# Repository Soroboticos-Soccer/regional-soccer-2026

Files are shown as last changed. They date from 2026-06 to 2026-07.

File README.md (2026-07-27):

# 🤖 Sorobóticos

<p align="center">
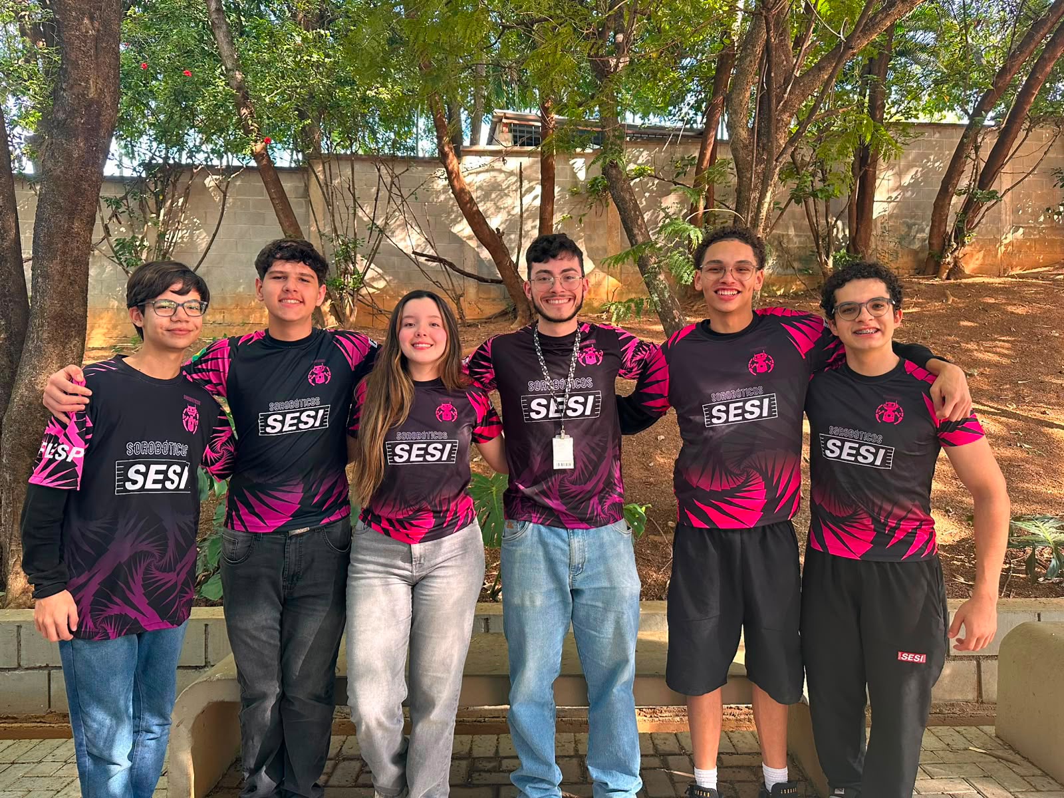
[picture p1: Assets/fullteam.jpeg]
  
</p>

<p align="center">
  <strong>Equipe de Robótica Competitiva • RoboCupJunior Soccer</strong>
</p>

---

# 👥 Sobre Nós

A **Sorobóticos Soccer** é uma equipe de robótica competitiva formada por estudantes apaixonados por tecnologia, engenharia e inovação. Nosso objetivo é desenvolver robôs autônomos capazes de atuar em partidas da modalidade **RoboCupJunior Soccer**, aplicando conhecimentos de programação, eletrônica, mecânica e manufatura digital.

A equipe acredita na aprendizagem prática como ferramenta de transformação, utilizando cada competição como uma oportunidade para evoluir tecnicamente, trabalhar em equipe e desenvolver soluções cada vez mais eficientes.

Atualmente nossos projetos são desenvolvidos com foco em:

* 🤖 Robótica Autônoma
* ⚙️ Engenharia Mecânica
* 🔌 Sistemas Embarcados
* 🧠 Algoritmos de Navegação
* 🎯 Visão Estratégica para Competições
* 🏆 RoboCupJunior Soccer

---

# 🏆 RoboCupJunior Soccer

Nosso robô foi desenvolvido para competir na categoria **Soccer Lightweight**, onde dois robôs autônomos atuam em uma partida de futebol utilizando sensores para localizar a bola, navegar pelo campo e executar estratégias ofensivas e defensivas.

---

# 📸 Nossa Equipe

<p align="center">
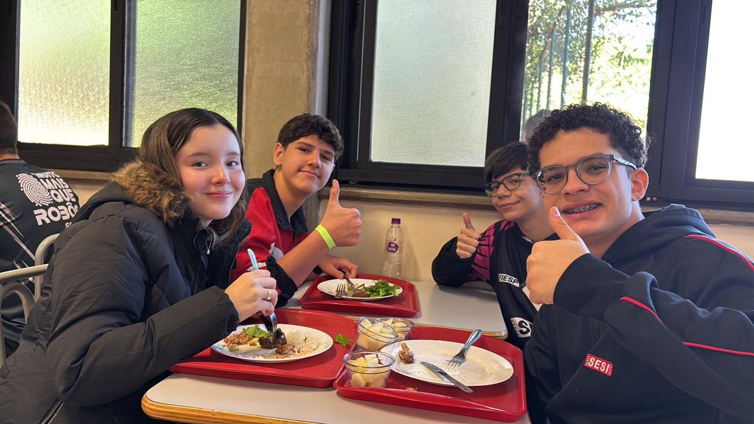
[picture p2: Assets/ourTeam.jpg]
  
</p>

---

# 🤖 Nosso Robô

<p align="center">
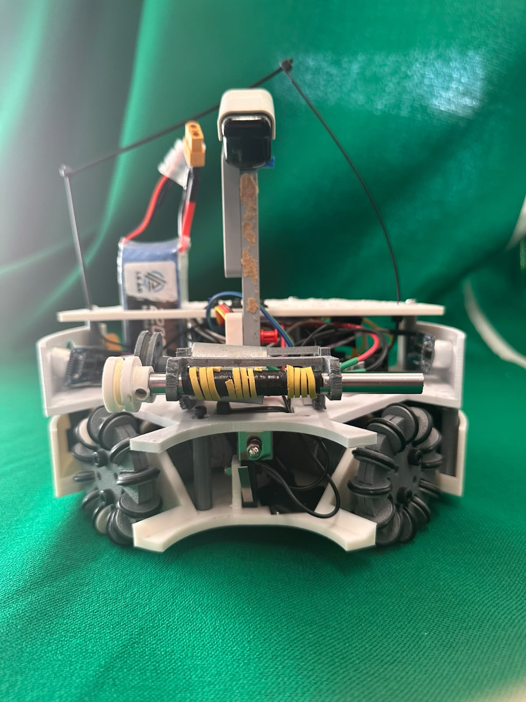
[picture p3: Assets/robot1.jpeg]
Robô Sorobóticos
  
</p>

---

# 🚀 Principais Características

### Movimentação Omnidirecional

O sistema utiliza quatro motores DC de 12V e rodas omni, permitindo movimentação em qualquer direção sem necessidade de girar o robô antes do deslocamento.

### Sistema de Dribbler

O dribbler foi desenvolvido para melhorar a captura e retenção da bola durante o jogo. O mecanismo utiliza transmissão por correias e polias para aumentar a velocidade de rotação e maximizar o controle da bola.

### Sistema de Kicker

O chute é realizado através de um mecanismo baseado em solenoide, projetado para alinhar o ponto de impacto ao centro da bola e aumentar a eficiência das finalizações.

### Posicionamento no Campo

O robô utiliza sensores ultrassônicos para estimar sua posição relativa dentro da arena e manter sua estratégia de navegação.

### Controle de Orientação

A orientação é monitorada continuamente por uma IMU, permitindo correções automáticas durante a movimentação e maior precisão nos deslocamentos.

---

# 🛠️ Hardware Utilizado

| Componente | Função |
| --- | --- |
| Arduino Mega 2560 R3 | Controle principal |
| Sensores IR TSOP4838 | Detecção da bola |
| Sensores Ultrassônicos HC-SR04 | Posicionamento |
| IMU BNO055 | Orientação |
| Drivers L298N | Controle dos motores |
| Motores DC 12V 500 RPM | Tração |
| Motor DC 12V 200 RPM | Dribbler |
| Solenoide | Kicker |
| Rodas Omni | Movimentação omnidirecional |

---

# 🏗️ Estrutura Mecânica

O chassi foi modelado em **Fusion 360** e fabricado através de impressão 3D.

### Materiais Utilizados

* TPU (Poliuretano Termoplástico)
* ABS (Acrilonitrila Butadieno Estireno)

O projeto foi otimizado para:

* Baixo centro de gravidade;
* Alta resistência a impactos;
* Facilidade de manutenção;
* Substituição rápida de componentes.

---

# 💡 Diferenciais do Projeto

### 🔧 Design Modular

O sistema foi projetado para permitir trocas rápidas de módulos críticos, reduzindo o tempo de manutenção entre partidas.

### 📡 Suporte Ajustável para Sensores IR

O suporte do sensor infravermelho permite ajustes mecânicos para adaptação a diferentes condições de campo.

### 🛡️ Chassi em TPU

A utilização de TPU proporciona absorção de impactos superior, aumentando a durabilidade da estrutura durante competições.

---

# 📈 Tecnologias Utilizadas

* Arduino IDE
* C++
* Fusion 360
* Impressão 3D
* BNO055
* HC-SR04
* TSOP4838

---

# 📧 Contato

**Sorobóticos Soccer**

📩 [soroboticossoccer@gmail.com](mailto:soroboticossoccer@gmail.com)
📬 Instagram: [@_soroboticos](https://www.instagram.com/_soroboticos/)

---

<p align="center">
Desenvolvido com dedicação pela equipe Sorobóticos⚽🤖
</p>

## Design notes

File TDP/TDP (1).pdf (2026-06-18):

Nome do Time

Qual é o nome do seu time?

Sorobóticos

Liga

De qual liga você está participando?

Infrared League

País

De onde vocês são?

Sorocaba, São Paulo, Brasil

Contato

Se outros times tiverem dúvidas sobre o seu robô, agora ou no futuro, qual(is) endereço(s) de e-mail nós podemos disponibilizar através desse documento para entrarem em contato?

E-mails aqui:

### - brunoproencasilva@gmail.com - gabriela.reche09@gmail.com - heitor.f.souto@gmail.com - hcabral.008@gmail.com

Redes Sociais

Link das redes sociais do time (se tiver)

Link aqui:

### https://www.instagram.com/_soroboticos?utm_source=ig_web_button_share_sheet&i

gsh=ZDNlZDc0MzIxNw== (https://www.instagram.com/_soroboticos?utm_source=ig_web_button_share_sheet&igsh=ZDNlZDc0MzIxNw==)

Foto do time

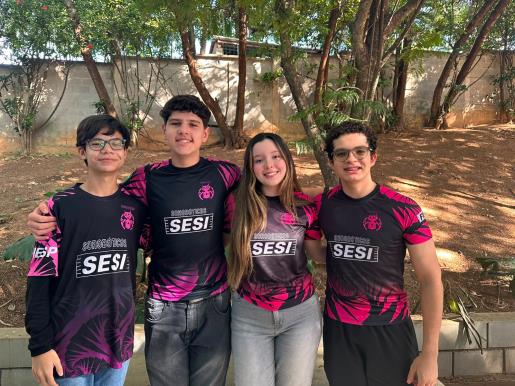
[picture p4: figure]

Membros & Funções

Qual é o nome de cada membro e quais são as suas funções:

- Bruno Proença: Integrador de Software;
- Henrique Cabral: Desenvolvedor de Software;
- Gabriela Reche: Projetista Mecânica;
- Heitor Ferreira: Integrador de Hardware.

Frequência de Reuniões

Com qual frequência o time de vocês se encontra?

Nos reunimos presencialmente de 3-5 vezes por semana. Além dos encontros presenciais, também mantemos comunicação frequente de forma online para discutir programação, eletrônica, mecânica e planejamento da estratégia.

Local das Reuniões

Onde vocês se reunem para trabalhar no robô?

Nos reunimos no espaço Fab Lab de nossa escola, onde temos acesso às ferramentas, equipamentos e recursos necessários para o desenvolvimento dos robôs.

Data de Início

Quando o seu time começou a trabalhar no robô desse ano?

Nós começamos a trabalhar no robô este ano, em maio, iniciando o planejamento das estratégias, o desenvolvimento mecânico e a programação dos sistemas do robô.

Competições Passadas

Em quais competições da RoboCupJunior vocês já participaram e em quais ligas?

A equipe já participou duas vezes da modalidade RoboCupJunior Rescue Maze, adquirindo experiência em programação, estratégia e resolução de desafios autônomos, ampliando nossos conhecimentos em robótica, trabalho em equipe e desenvolvimento de projetos tecnológicos.

Para dois integrantes da equipe, esta será a primeira experiência em competições práticas de robótica.

Contribuição do Mentor

Quais partes do trabalho que mais tiveram a contribuição do mentor?

Nosso mentor teve uma contribuição importante principalmente no ensino de modelagem 3D e utilização do Fusion, além de auxiliar no planejamento e organização do projeto. Ele também nos orientou em decisões relacionadas ao design do robô, estratégias de jogo e desenvolvimento geral da equipe, facilitando nosso aprendizado e guiando o grupo durante todas as etapas do projeto.

Gerenciamento de Tarefas

Como vocês gerenciaram as tarefas da equipe?

No início de cada semana, utilizamos um quadro Kanban para organizar e gerenciar as tarefas da equipe. Por meio dessa metodologia, distribuímos as atividades entre os integrantes, acompanhávamos o progresso do projeto e definíamos prioridades para as tarefas mais importantes, garantindo uma melhor organização, comunicação e eficiência no desenvolvimento do robô.

Ferramentas de IA

Quais ferramentas de IA vocês utilizaram?

Utilizamos ferramentas de inteligência artificial como ChatGPT, Gemini e Claude para auxiliar no desenvolvimento do projeto, principalmente na programação de novos componentes, otimização de algoritmos e identificação de erros no código.

Robô 1 Geral

Vista Geral do Robô 1

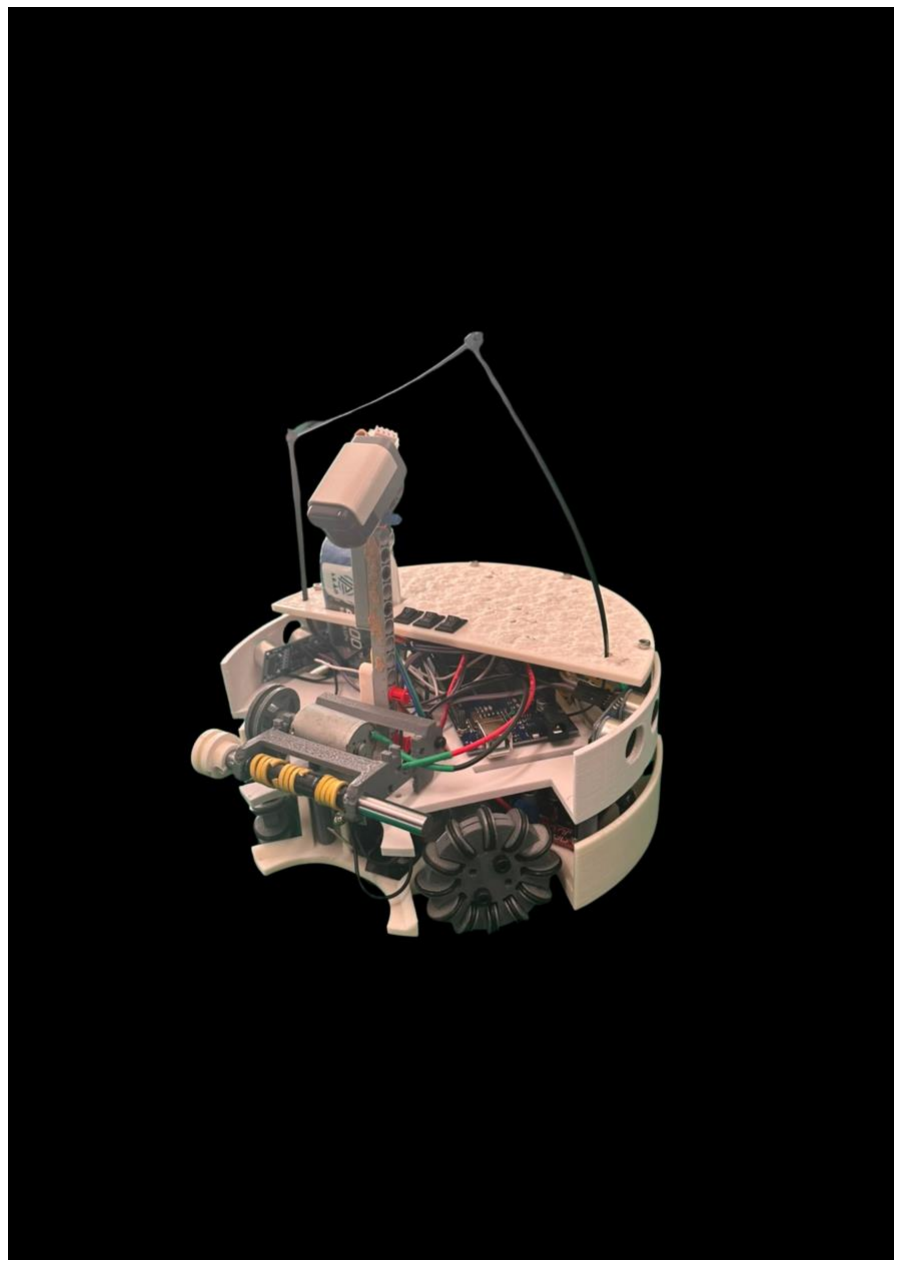
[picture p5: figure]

Robô 1 Frente

Vista Frontal do Robô 1

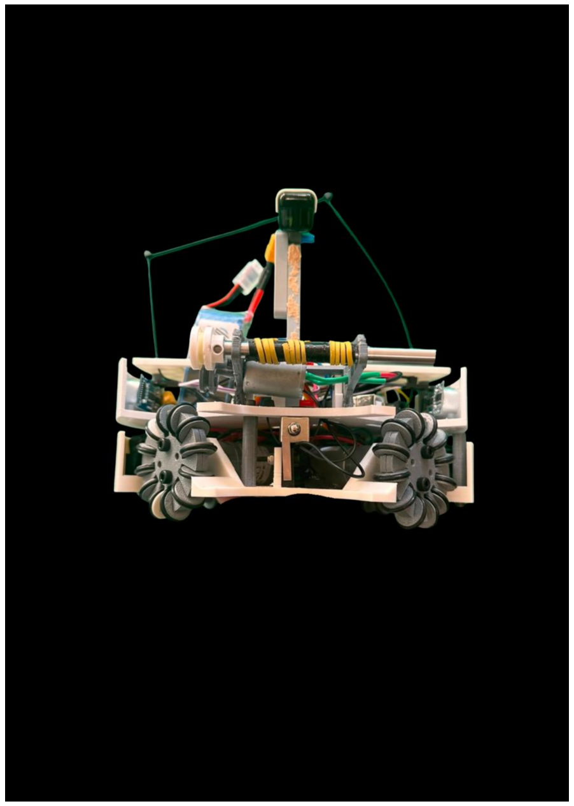
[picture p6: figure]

Robô 1 Traseira

Vista Traseira do Robô 1

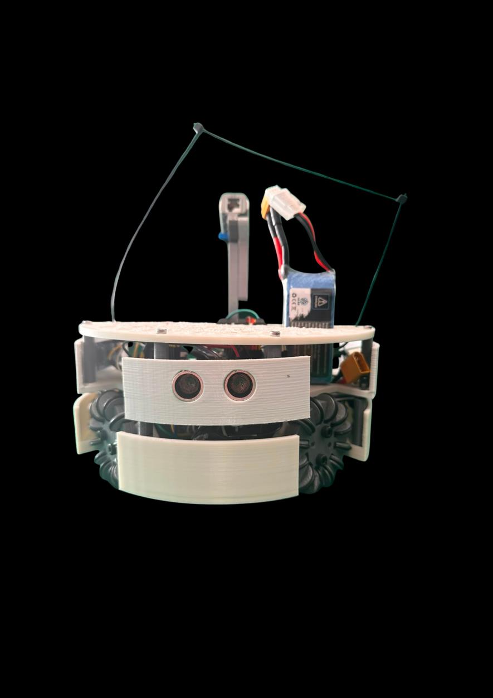
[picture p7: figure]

Robô 1 Superior

Vista Superior do Robô 1

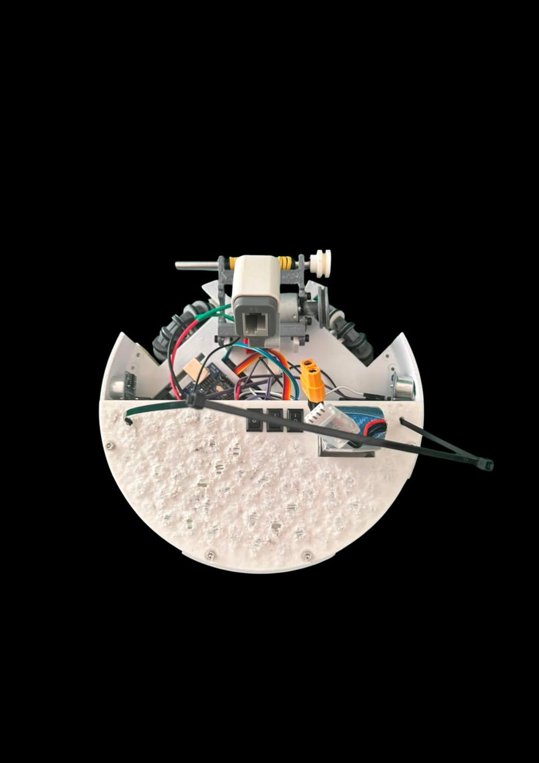
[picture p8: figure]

Robô 1 Inferior

Vista Inferior do Robô 1

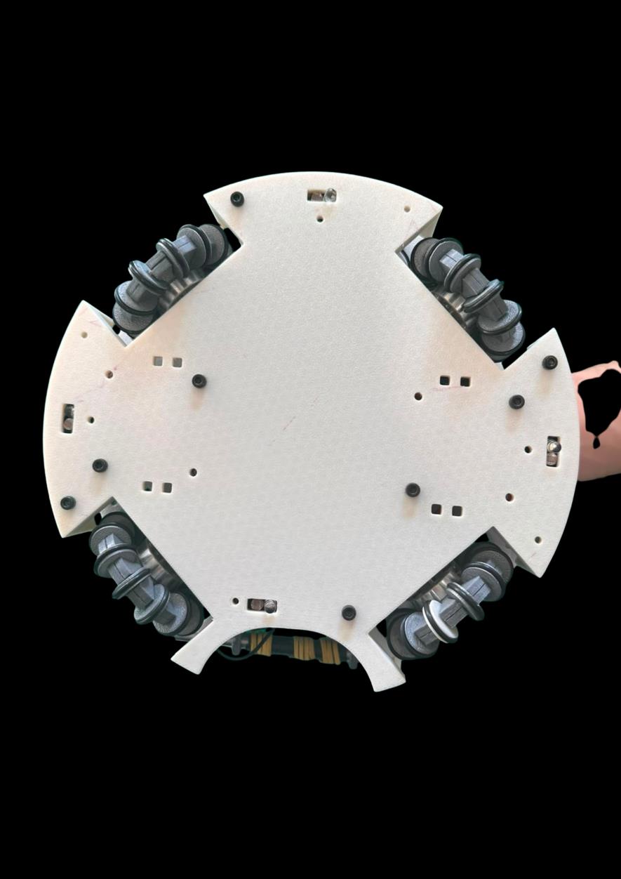
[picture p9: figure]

Robô 1 Lateral Direita

### Vista Lateral Direita do Robô 1

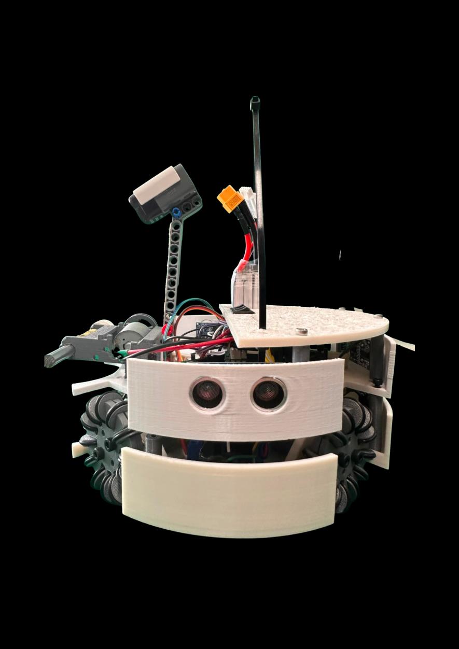
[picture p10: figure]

Robô 1 Lateral Esquerda

Vista Lateral do Robô 1

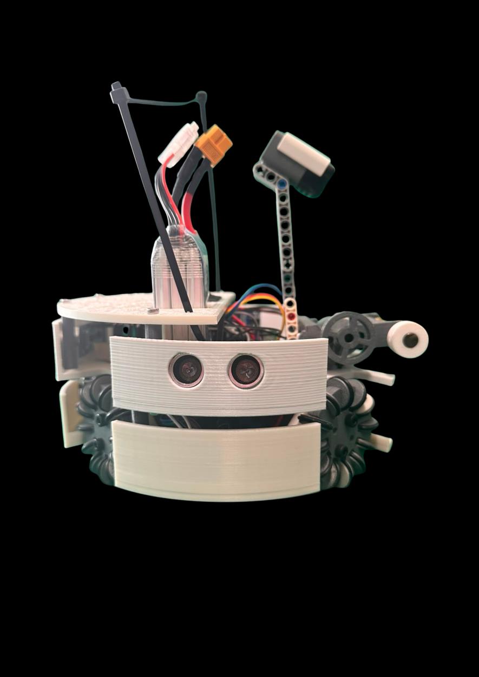
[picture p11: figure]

Posicionamento e Movimentação

Como você localiza o robô dentro do campo e como você utiliza essa localização para movimentá-lo?

Nosso robô utiliza sensores LDR, sensores ultrassônicos e sensor giroscópio para orientação e localização dentro do campo. O sensor giroscópio é responsável por manter os robôs sempre orientados em direção ao lado adversário, garantindo maior estabilidade e precisão durante a movimentação.

Já os sensores ultrassônicos permitem estimar a posição do robô no campo por meio da obtenção de coordenadas aproximadas nos eixos X e Y. Com essas informações, conseguimos implementar movimentações mais estratégicas, como direcionar o robô para posições específicas durante o ataque, facilitando o alinhamento e a realização dos chutes.

Durante o desenvolvimento, tivemos bastante cautela na implementação dos sensores ultrassônicos devido à possibilidade de interferências causadas por outros robôs e pela própria bola, realizando testes e ajustes para aumentar a confiabilidade da leitura durante as partidas.

Robô 2 Geral

Vista Geral do Robô 2

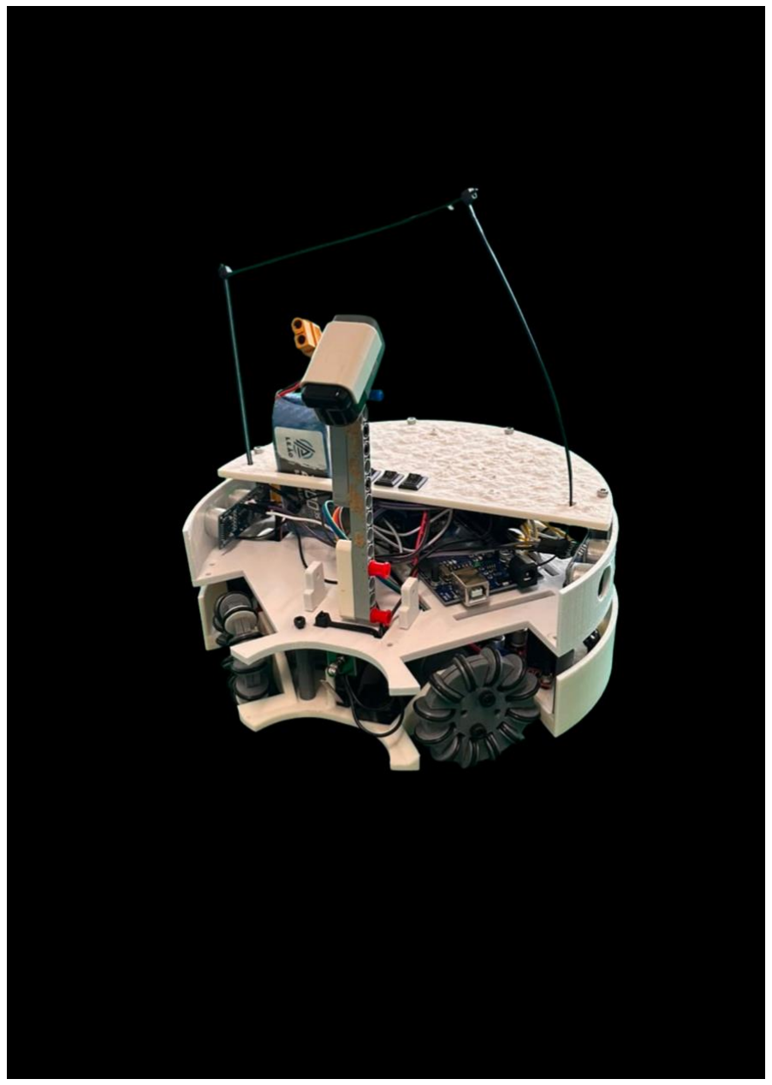
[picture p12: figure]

Frente Robô 2

Vista Frontal do Robô 2

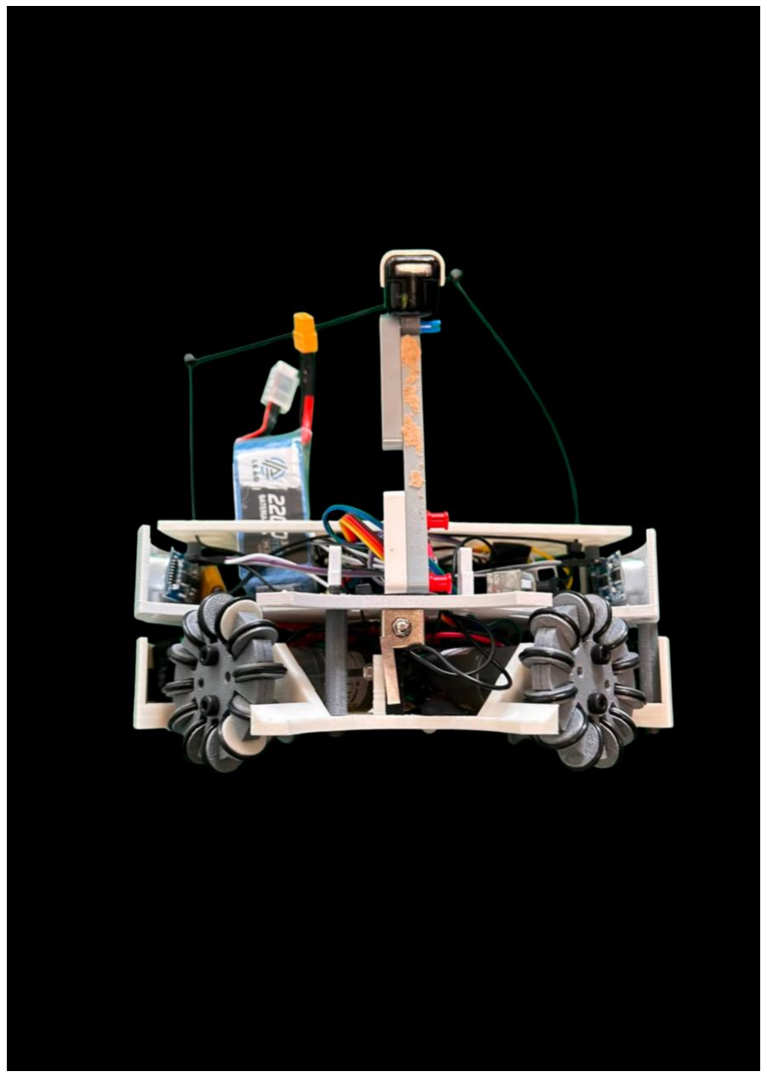
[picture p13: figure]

Robô 2 Traseira

Vista Traseira do Robô 2

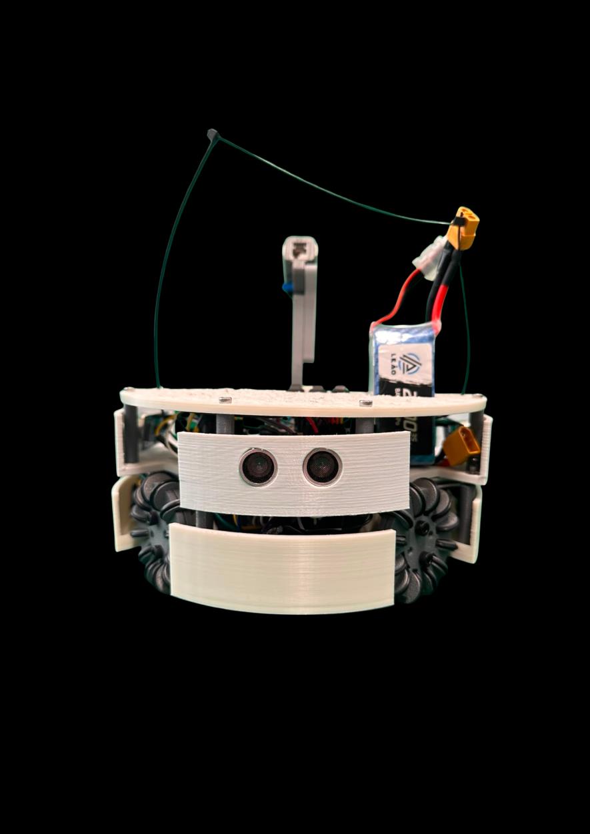
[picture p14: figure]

Robô 2 Superior

Vista Superior do Robô 2

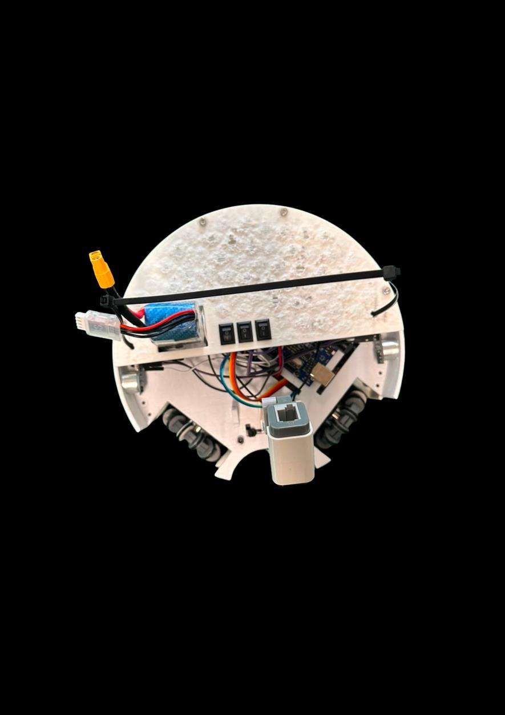
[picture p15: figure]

Robô 2 Inferior

Vista Inferior do Robô 2

Robo2 Lateral Direita

Vista Lateral Direita do Robô 2

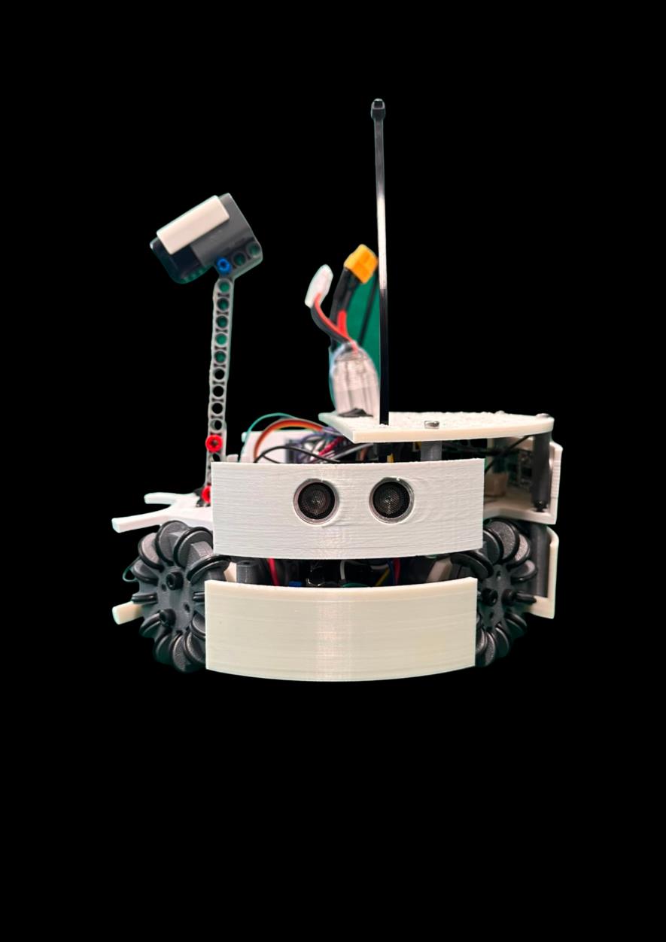
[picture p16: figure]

Robô 2 Lateral Esquerda

Vista Lateral Esquerda do Robô 2

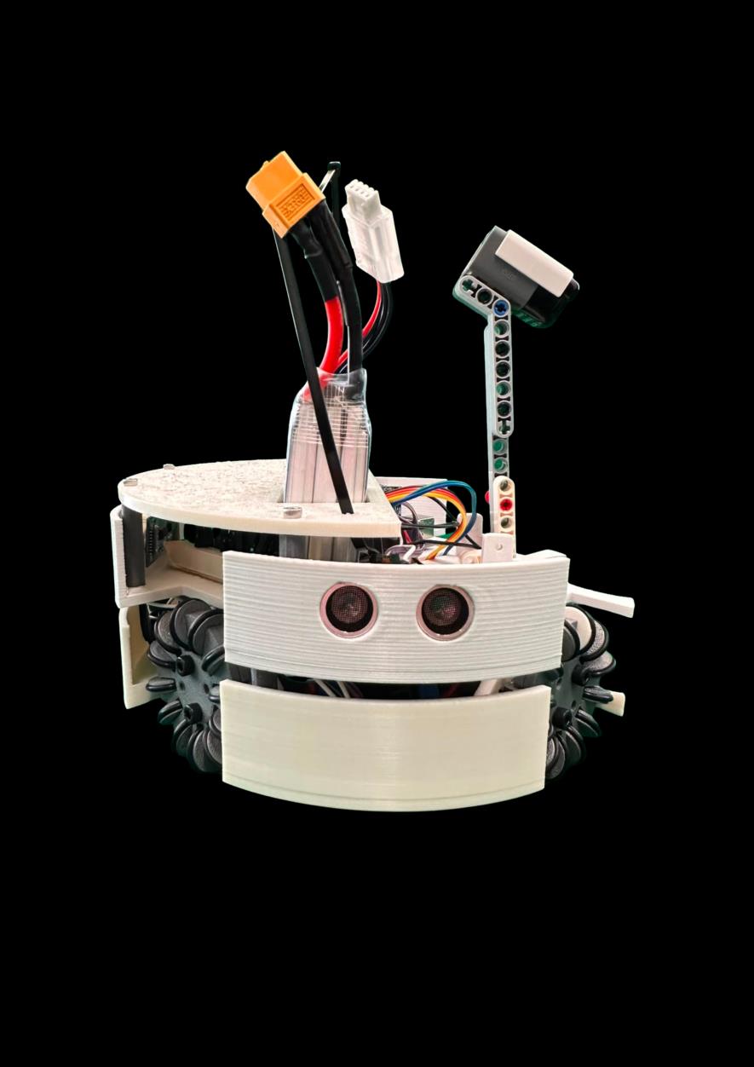
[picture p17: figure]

Design Mecânico

Como vocês fizeram o design das partes mecânicas do seu robô?

Para o desenvolvimento das partes mecânicas, utilizamos o Fusion 360 para modelar o chassi e os principais componentes do robô. Diversas iterações de projeto e testes foram realizadas ao longo do desenvolvimento, permitindo otimizar a estrutura e o desempenho mecânico do sistema.

A fabricação das peças foi realizada por impressão 3D, garantindo alta precisão e eficiência na prototipagem. Também conduzimos um estudo dos materiais e dos padrões de preenchimento (infill), optando pela estrutura do tipo favo de mel

(honeycomb) devido à sua excelente relação entre resistência mecânica e peso reduzido.

O TPU (Poliuretano Termoplástico) foi empregado em regiões sujeitas a impactos, aproveitando suas propriedades flexíveis e sua capacidade de absorção de energia. Já o ABS (Acrilonitrila Butadieno Estireno) foi utilizado em componentes que exigem maior rigidez e resistência mecânica, como o dribbler.

O projeto final adotou um chassi circular com posições específicas para cada componente, facilitando a organização interna e a manutenção. Recursos visuais também foram incorporados para simplificar a identificação dos elementos eletrônicos e mecânicos. Além disso, peças como as rodas e o dribbler foram projetadas no Fusion 360 para garantir perfeita integração ao conjunto. A distribuição dos componentes foi planejada para manter um baixo centro de gravidade, aumentando a estabilidade do robô durante deslocamentos, colisões e mudanças rápidas de direção. Essa combinação de design, materiais e técnicas de fabricação resultou em uma estrutura leve, resistente e de fácil manutenção.

Método de Construção

Como você construiu o seu design?

Como vocês construíram o seu design?

Nossa estratégia de desenvolvimento consistiu na utilização de um robô de testes, que foi modificado manualmente ao longo do projeto. A estrutura foi lixada, ajustada e adaptada diversas vezes até que obtivéssemos um resultado próximo ao esperado. Essa abordagem permitiu realizar testes mecânicos e de programação sem a necessidade de imprimir um novo chassi a cada alteração, reduzindo significativamente o consumo de filamento e o tempo de desenvolvimento.

Após a validação dos principais conceitos no robô de testes, fabricamos o chassi definitivo por impressão 3D, incorporando todas as melhorias identificadas durante os experimentos. As demais peças produzidas por manufatura aditiva, como suportes, rodas e componentes do dribbler, seguiram a mesma metodologia: inicialmente eram testadas e ajustadas em protótipos, e somente após sua validação eram impressas em sua versão final.

Em seguida, realizamos a montagem completa do robô, instalando os sistemas mecânicos, eletrônicos e de controle. Por fim, novos testes foram conduzidos para verificar a integração entre os componentes e garantir o desempenho, a estabilidade e a confiabilidade do sistema durante as partidas.

Motores e Razão

Quantos motores vocês usaram e por quê?

A movimentação do robô é realizada por quatro motores de corrente contínua de 12 V e 500 RPM, cada um acoplado a uma roda omni, permitindo deslocamentos em múltiplas direções e maior liberdade de movimentação. Para o sistema de dribbler, foi empregado um motor de corrente contínua de 12 V e 200 RPM, responsável pela rotação do dribbler, que auxilia no controle e na retenção da bola durante as partidas.

Design do Kicker

Se o robô tiver um kicker, explique como foi projetado e contruído o mecanismo do kicker?

Em nosso robô, o kicker foi projetado para aumentar a potência e a eficiência dos chutes, proporcionando maior velocidade de saída da bola e contribuindo para a precisão das jogadas. O mecanismo foi desenvolvido de forma a alinhar o ponto de impacto com o centro da bola, maximizando a transferência de energia durante o chute.

Para isso, o kicker foi instalado logo abaixo do dribbler, entre os dois chassis do robô, sendo o único componente localizado neste local no robô. garantindo um posicionamento centralizado em relação à bola quando esta é controlada pelo sistema de drible. Essa configuração reduz desalinhamentos no momento do impacto, melhora a consistência dos chutes e contribui para um desempenho mais confiável durante as partidas.

Além disso, sua estrutura foi projetada para ser compacta e robusta, permitindo integração eficiente com os demais sistemas do robô sem comprometer a estabilidade ou a mobilidade da plataforma.

Design do Dribbler

Se o robô tiver um dribbler, explique como vocês projetaram e construiram o mecanismo do dribbler. ... If your robot has a dribbler, explain how you designed and built the mechanics of the dribbler.

O dribbler foi projetado para garantir o controle eficiente da bola durante a movimentação do robô. O mecanismo é composto por um eixo metálico acionado por um motor de alta rotação, sendo o eixo revestido com fita dupla face para aumentar o atrito e, consequentemente, a aderência durante o contato com a bola.

Para potencializar o desempenho do sistema, utilizamos um conjunto de polias e correias para transmitir o movimento do motor ao eixo metálico, configurado de forma a aumentar a velocidade de rotação do dribbler. Essa solução permitiu obter uma maior velocidade tangencial na superfície de contato com a bola, melhorando sua captação e condução.

Durante o processo de desenvolvimento, o dispositivo foi modelado de forma a maximizar a área de contato entre o dribbler e a bola, proporcionando maior tração e estabilidade na condução. Seu posicionamento e geometria foram cuidadosamente definidos para manter a bola próxima ao robô, reduzindo a possibilidade de perda de controle durante acelerações, frenagens e mudanças bruscas de direção.

Inovação Mecânica

Inovação Mecânica

O desenvolvimento mecânico do nosso robô priorizou soluções que garantissem manutenibilidade rápida, adaptabilidade às condições da arena e eficiência dinâmica. Destacam-se três pilares fundamentais no nosso design:

- Design Modular de Alta Eficiência: Desenvolvido no software Fusion 360 e fabricado via impressão 3D em TPU, o chassi foi estruturado sob uma perspectiva estritamente modular. Esse arranjo estratégico permite que os conjuntos de rodas omnidirecionais ou o módulo do dribbler sejam completamente substituídos em menos de dois minutos, garantindo agilidade em reparos críticos nos intervalos entre as partidas.
- Suporte Ajustável para o Sensor IR: O suporte que aloja o receptor infravermelho conta com um sistema de regulagem geométrica. Essa flexibilidade mecânica facilita o processo de calibração física do componente, permitindo adequar rapidamente o ângulo de leitura do sensor para otimizar o rastreamento da bola de acordo com as variações e características específicas de diferentes campos.

Diagrama da Eletrônica

Forneça-nos um diagrama da eletrônica do seu robô

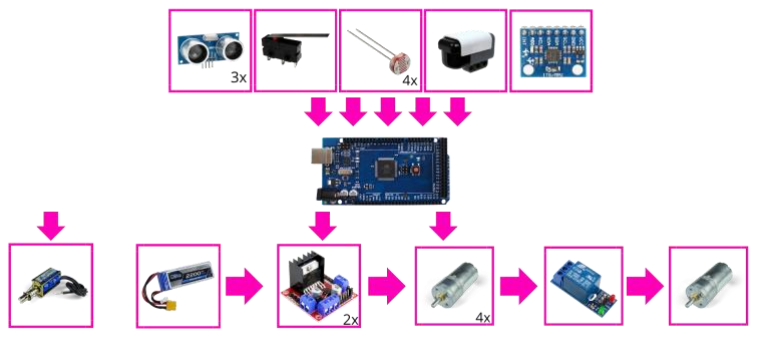
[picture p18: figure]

Circuito de Energia

Como o circuito de energia funciona?

Utilizamos duas baterias independentes para distribuir a alimentação do robô de forma mais eficiente. Uma bateria de 11,1 V é dedicada aos motores de movimentação e ao dribbler, garantindo corrente suficiente para os componentes de maior consumo. A segunda bateria, de 7,4 V, alimenta o Arduino, que por sua vez fornece energia aos sensores e demais componentes eletrônicos de controle. Essa separação reduz interferências causadas pelos motores, aumentando a estabilidade e a confiabilidade do sistema durante as partidas.

Circuito do Motor

Como você controla os motores? Explique os circuitos que você utiliza para isso.

Foram utilizadas duas placas driver L298N para o acionamento dos motores de tração e uma terceira placa dedicada ao sistema do dribbler. A interface de controle é realizada por meio de um Arduino, responsável pela geração dos sinais de modulação por largura de pulso (PWM). Cada motor é acionado por três pinos de controle, sendo dois destinados à definição do sentido de rotação e um utilizado para o controle da velocidade por PWM, permitindo um ajuste preciso do desempenho do sistema.

Microcontrolador & Razão

Qual tipo de microcontrolador ou placa vocês usaram para o robô? Por que você decidiu usar essa peça para o seu robô? Se o usou mais de um processador, explique-os separadamente

Para o controlo central do robô, a equipa selecionou a placa Arduino Mega 2560 R3. A escolha deste microcontrolador baseou-se na sua robustez, ampla capacidade de conectividade e fiabilidade no processamento de dados em tempo real, atendendo perfeitamente às exigências dinâmicas da RoboCup:
- Capacidade de Processamento e Memória: Equipado com o chip ATmega2560 e 256 KB de memória Flash, o controlador possui a capacidade ideal para armazenar e executar com fluidez toda a lógica de jogo, os algoritmos de tomada de decisão e a filtragem das leituras dos sensores, garantindo um tempo de resposta imediato em campo.
- Ampla Disponibilidade de Portas (I/O): Com 54 pinos digitais e 16 entradas analógicas, a placa permite a integração simultânea e direta de todos os periféricos do projeto. Isto inclui a rede de sensores (recetor IR TSOP4838, IMU BNO055 e sensores de luminosidade) e os atuadores (motores de tração de 12V e o sistema do dribbler), eliminando a necessidade de expansores de portas que poderiam introduzir latência.
- Padronização e Robustez (Revisão R3): O formato padrão da revisão R3 oferece excelente estabilidade mecânica e elétrica. Esta característica mecânica facilita o acoplamento de shields dedicados ou placas de circuito impresso (PCBs) personalizadas para a distribuição de energia e acionamento dos motores, o que otimiza a organização interna do chassi de TPU e assegura ligações firmes e resistentes aos impactos das partidas.

Detecção da Bola

Como o seu sensor de detecção da bola e/ou sua câmera(s) funciona?

Para a identificação da bolinha de infravermelho, o robô atacante utiliza o sensor HiTechnic InfraRed Seeker. Esse sensor é responsável por detectar a direção do sinal infravermelho emitido pela bolinha e auxiliar na orientação do robô, guiando-o de forma mais precisa em sua direção. Já o robô goleiro utiliza o sensor TSOP4838, empregado na recepção de sinais infravermelhos modulados em 38 kHz para a detecção da bola. Dessa forma, cada robô adota uma estratégia distinta de sensoriamento infravermelho, adequada à sua função dentro da equipe, contribuindo para um melhor desempenho durante as partidas.

A partir dessas duas variáveis, nosso robô consegue identificar com precisão a posição e a distância da bola, permitindo uma movimentação eficiente e confiável para alcançá-la durante as partidas.

Detecção da Linha

Como o circuito de detecção de linha do seu robô funciona?

Utilizamos quatro sensores LDR posicionados estrategicamente para garantir que o robô não ultrapasse a linha branca do campo. Cada sensor é alimentado com 5V e conectado a um circuito pull-down utilizando um resistor de 10 kΩ. A saída de cada sensor é ligada a uma entrada analógica do microcontrolador, permitindo a leitura contínua dos valores de luminosidade.

Quando os sensores detectam a diferença de reflexão entre o campo escuro e a linha branca, o microcontrolador interpreta essa variação e executa rapidamente movimentos corretivos para impedir que o robô saia da área de jogo.

Sensores de Posição/Navegação

Quais sensores vocês usaram para a navegação e como eles são conectados com o processador? Quais sensores vocês para se posicionar no campo? E quanto ao senso de direção do robô?

Para a navegação e posicionamento no campo, utilizamos três sensores ultrassônicos conectados diretamente ao microcontrolador do robô por meio de portas digitais de entrada e saída. Esses sensores medem continuamente a distância até as bordas da quadra, permitindo estimar a posição do robô nos eixos X e Y. Com essas informações, o sistema consegue determinar sua localização aproximada dentro do campo e ajustar sua trajetória quando necessário.

Além dos sensores ultrassônicos, utilizamos o sensor inercial MPU6050, que integra acelerômetro e giroscópio. Esse sensor é conectado ao processador através da comunicação I²C e fornece informações sobre a orientação angular do robô em

tempo real.

O MPU6050 é responsável pelo senso de direção do robô, permitindo a realização de giros precisos e o controle do ângulo do chute.

Circuito do Kicker

Como vocês conduziram o sistema do kicker? Como como o circuito do kicker faz ele funcionar?

Utilizamos um sistema de kicker baseado em um solenoide, responsável por gerar a força necessária para impulsionar a bola. O solenoide recebe alimentação diretamente da bateria do robô, enquanto o acionamento é controlado por um relé conectado a uma porta digital do microcontrolador.

Quando o microcontrolador identifica a condição ideal para o chute, ele envia um sinal ao relé, permitindo a passagem de corrente para o solenoide. Isso gera um movimento rápido e forte no mecanismo de chute, possibilitando finalizações mais eficientes durante as partidas.

Circuito do Dribbler

Como o sistema do seu dribbler funciona? Quais componentes e circuitos vocês usaram para controlá-lo?

We designed a dribbler system to help the robot capture and maintain control of the ball while moving, allowing it to perform passes, dribbles, shots, and both offensive and defensive maneuvers with greater precision. The dribbler also prevents the ball from rolling away or being easily taken by opponents. It is powered by a motor connected to the L298N board, which drives a gear system to keep the ball securely in place. When the robot approaches the opponent’s goal, the motor reverses direction, releasing the ball to attempt a goal.

PCB

PCB do robô .... PCB of your robot

Não utilizamos placa de circuito personalizado.

Inovação

Inovações

O elemento de maior orgulho no desenvolvimento do nosso robô é o chassi personalizado, projetado no Fusion 360 e impresso em 3D utilizando Poliuretano Termoplástico (TPU) rosa. A utilização deste material maleável e de alta tenacidade otimiza significativamente a absorção de impactos mecânicos e estabelece um casulo protetor altamente eficiente e resiliente para toda a eletrônica e rede de sensores embarcados.

O resultado é uma estabilidade estrutural notável, reduzindo drasticamente o risco de fraturas ou desalinhamentos físicos que tipicamente ocorrem com o uso de plásticos rígidos convencionais sob as constantes colisões de alta velocidade da modalidade Soccer. Além disso, as propriedades elásticas e a flexibilidade controlada do TPU permitiram projetar geometrias de encaixe sob pressão, o que simplifica consideravelmente a manutenção interna e acelera a substituição rápida de componentes nos boxes entre as partidas.

Controle do Motor

Como o processador é usado para controlar os motores?

A arquitetura de controle do robô é baseada no microcontrolador Arduino Mega 2560 R3, que se comunica com dois módulos driver L298N em ponte H dupla para gerenciar o sistema de rotação. Cada motor de corrente contínua é acionado por três linhas de controle: dois pinos digitais (IN1 e IN2) definem o sentido de rotação, enquanto um pino de habilitação (EN) regula a velocidade e a potência via sinais de Modulação por Largura de Pulso (PWM) do microcontrolador.

Método de Detecção da Bola

Como o robô detecta a bola? Como o robô lê os dados do sensor de detecção da bola ou da câmera?

Para a localização da bola em campo, o robô utiliza uma estratégia de rastreamento baseada em sensores receptores de infravermelho TSOP4838, componentes fundamentais para detectar com precisão os sinais de IR modulados emitidos pela bola oficial da RoboCup:

- Captação de Sinais Modulados: O sensor TSOP4838 é projetado especificamente para sintonizar a frequência de modulação da bola (frequentemente em 38 kHz), o que mitiga a interferência de fontes de luz externa e da iluminação ambiente do local da competição.
- Processamento de Dados e Direção: Os sinais captados pelos receptores são enviados diretamente para o Arduino Mega 2560 R3. O microcontrolador processa essas leituras em tempo real, mapeando a intensidade e a temporização dos pulsos captados para calcular valores numéricos correspondentes à direção e proximidade da bola em relação ao eixo central do robô.
- Integração com o Código: Por meio de rotinas de software e filtros digitais implementados na IDE do Arduino, os dados brutos dos sensores são
convertidos | rapidamente | em | informações | direcionais | limpas. | Esse
processamento contínuo serve como entrada imediata para o algoritmo de navegação omnidirecional, permitindo que o robô reaja instantaneamente a mudanças na trajetória da bola com alta agilidade.

Algoritmo de Condução da Bola

Como o algoritmo de pegar a bola funciona? Há alguma diferença entre os robôs na forma que eles se movem em direção à bola?

Ambos os robôs utilizam os valores de direção e intensidade fornecidos pelo sensor de bola para localizar e se mover em direção a ela. No entanto, cada um possui uma estratégia diferente de acordo com sua função na equipe.

O robô atacante procura se posicionar atrás da bola, mantendo-a entre ele e o gol adversário. Isso facilita o controle da bola e melhora a eficiência dos ataques, evitando rotações desnecessárias durante a movimentação.

Já o robô goleiro move-se na direção da bola para realizar bloqueios, mas sua movimentação é limitada à área defensiva. Ele nunca sai da linha de pênalti, garantindo que permaneça em uma posição adequada para proteger o gol.

Algoritmo da Linha

Como o seu robô identifica a linha para se manter dentro do campo? Quais algoritmos foram usados para evitar que o robô saia da area?

O robô utiliza sensores de refletância LDR posicionados na parte inferior da estrutura para detectar as linhas brancas que delimitam o campo. A leitura desses sensores é realizada continuamente no loop principal de controle, garantindo resposta rápida a qualquer aproximação das bordas.

O algoritmo implementado é baseado em uma lógica reativa de prioridade. Sempre que um dos sensores identifica a linha (valor acima do limiar definido durante a calibração), o evento recebe prioridade sobre as demais ações do robô. Nesse momento, o sistema interrompe temporariamente o comportamento atual e executa um movimento na direção oposta ao sensor acionado.

Algoritmo de Gols

Quais algoritmos vocês usaram para marcar gols? Como vocês usaram o dribbler e o kicker para conduzir a bola?

Quando o robô detecta que está com posse de bola por meio do sensor de switch, ele inicia automaticamente o modo de ataque. A partir desse momento, o comportamento ofensivo varia de acordo com a posição do robô em campo, podendo avançar pela esquerda, pela direita ou diretamente em direção ao gol caso já esteja em uma posição favorável.

Durante a condução da bola, o robô pode se mover de costas utilizando o dribbler para manter o controle da bola e aumentar a distância em relação aos adversários, reduzindo o risco de perda de posse. Quando atinge uma distância ou ângulo adequado em relação ao gol, o robô realiza o alinhamento final por meio de rotação e aciona o kicker para efetuar o chute.

Algoritmo de Defesa

Quais algoritmos vocês usaram para impedir que o time adversario marque gols? Como os seus robôs defendem o proprio gol?

Quando o robô atacante não está com a posse da bola, ele se desloca continuamente em direção à sua posição para tentar recuperá-la. Esse comportamento também ajuda a pressionar o adversário e dificultar sua progressão, sem recuar excessivamente no campo para não interferir na atuação do goleiro.

O robô goleiro permanece prioritariamente posicionado na linha de pênalti, garantindo a proteção constante do gol. A partir dessa posição, ele acompanha a movimentação da bola e realiza bloqueios quando necessário. Em situações específicas, quando a bola está próxima e parada por um curto período, o goleiro avança temporariamente para afastá-la ou chutá-la em direção ao campo adversário, retornando em seguida à sua posição defensiva.

Comunicação do Robô

Os seus robôs se comunicam entre si? Como vocês usam essa comunicação para obter vantagem?

Os robôs não possuem comunicação direta entre si durante a partida. No entanto, cada um é programado com funções bem definidas, atacante e goleiro, o que garante um comportamento coordenado e complementar em campo. Essa divisão de papéis evita conflitos de decisão e reduz a chance de os robôs se atrapalharem, permitindo que atuem de forma harmônica.

Link GitHub

Link do GitHub

### https://github.com/Soroboticos-Soccer/regional-soccer-2026

Lista de Materiais

Lista de Materiais

ListaPreço.xlsx (https://sesisenaispedu-my.sharepoint.com/:x:/g/personal/antoni_frigerio_portalsesisp_org_br/IQARvzUoNFhvR7zJtImBCNMOAaJihk4XXiH-QJTbcqsfziY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)

Custo

Quanto custou para construir o robô?

Robôs (componentes em uso): 2169 BRL;

Experimentos (falhas de construção, quebra, hardware.): 2847 BRL;

Fundos

Como vocês conseguiram os fundos para construir o robô

Todos os gastos foram custeados pela escola SESI

Acessibilidade

Quão accessivel foi para completar o RoboCupJunior Soccer

Conferir Respostas

Vocês conferiu todas as suas respostas?

Sim!

Consentimento de Publicação

Nos publicamos os TDPs e os Posters durante ou depois da competição como descrito no início

Endereço de E-mail

Endereço de e-mail

### soroboticossoccer@gmail.com

Arquivo TDP

### https://github.com/Soroboticos-Soccer/regional-soccer-2026/tree/main/TDP

Extra Column

Column 67

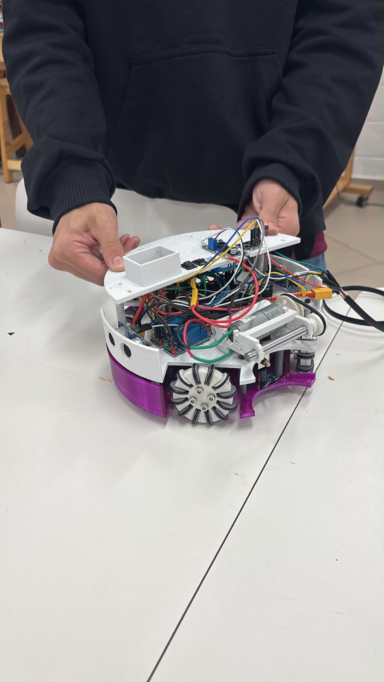
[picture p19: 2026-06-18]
Assets/robot.jpg

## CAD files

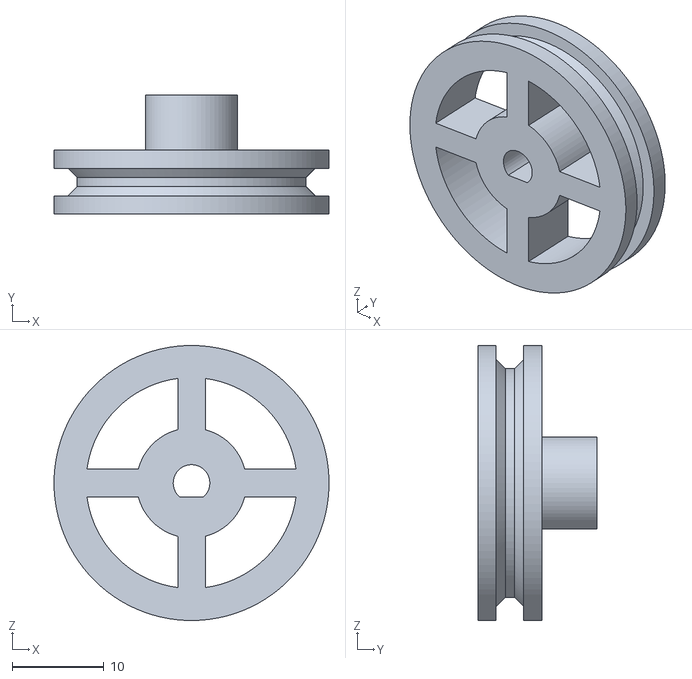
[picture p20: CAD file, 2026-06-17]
Projetos Mecânicos/polia_3cm (1).stl
30.0 x 13.0 x 30.0

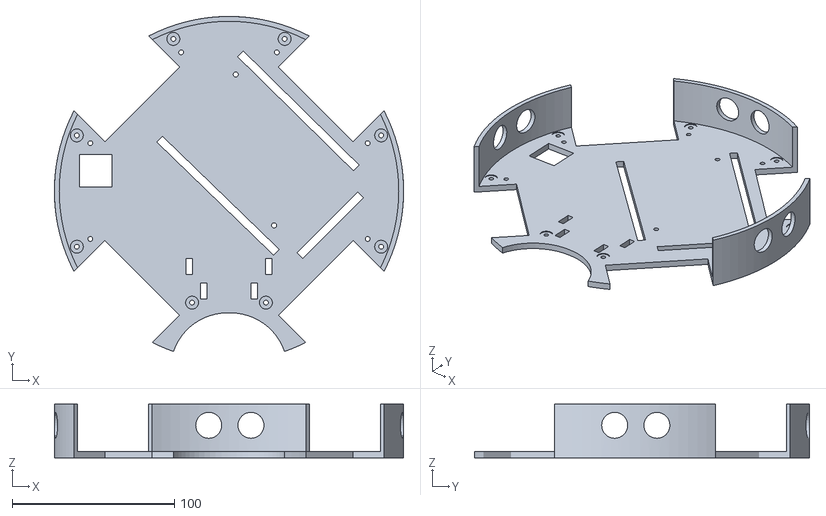
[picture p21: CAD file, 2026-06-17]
Projetos Mecânicos/chassi_soccer_meio.stl
214.9 x 206.2 x 33.0

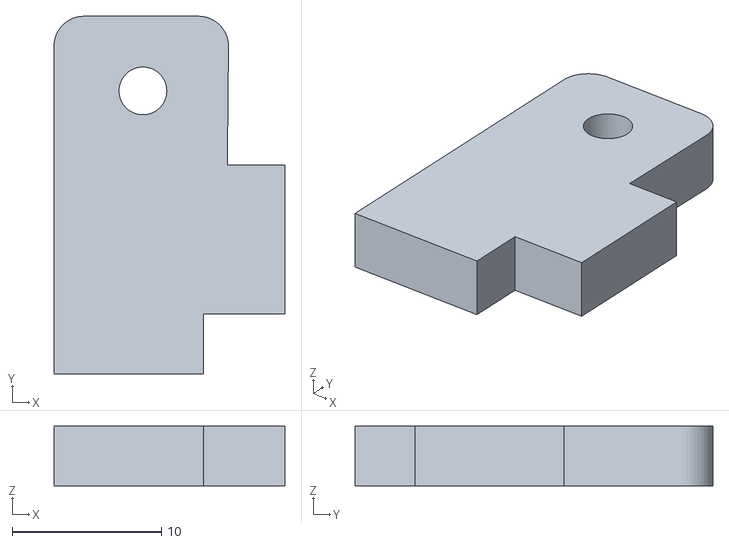
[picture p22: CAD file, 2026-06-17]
Projetos Mecânicos/dribler teste (6).stl
15.5 x 23.9 x 4.00

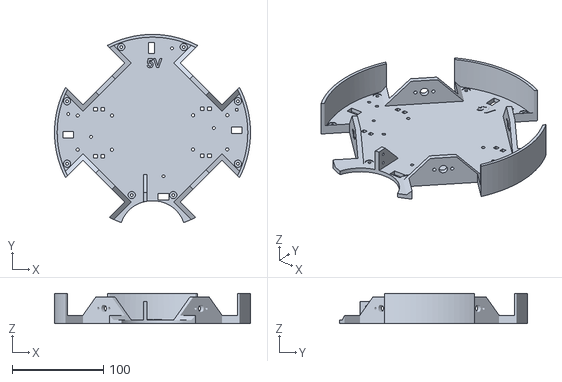
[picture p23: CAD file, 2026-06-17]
Projetos Mecânicos/chassi_soccer_v2.stl
214.9 x 206.2 x 33.0

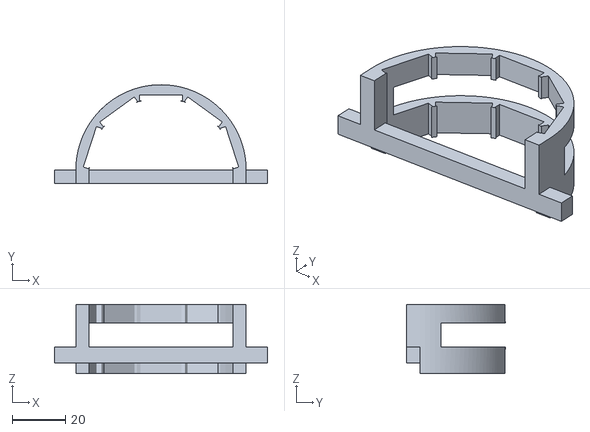
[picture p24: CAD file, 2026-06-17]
Projetos Mecânicos/seeker_goleiro.stl
80.0 x 37.0 x 26.0

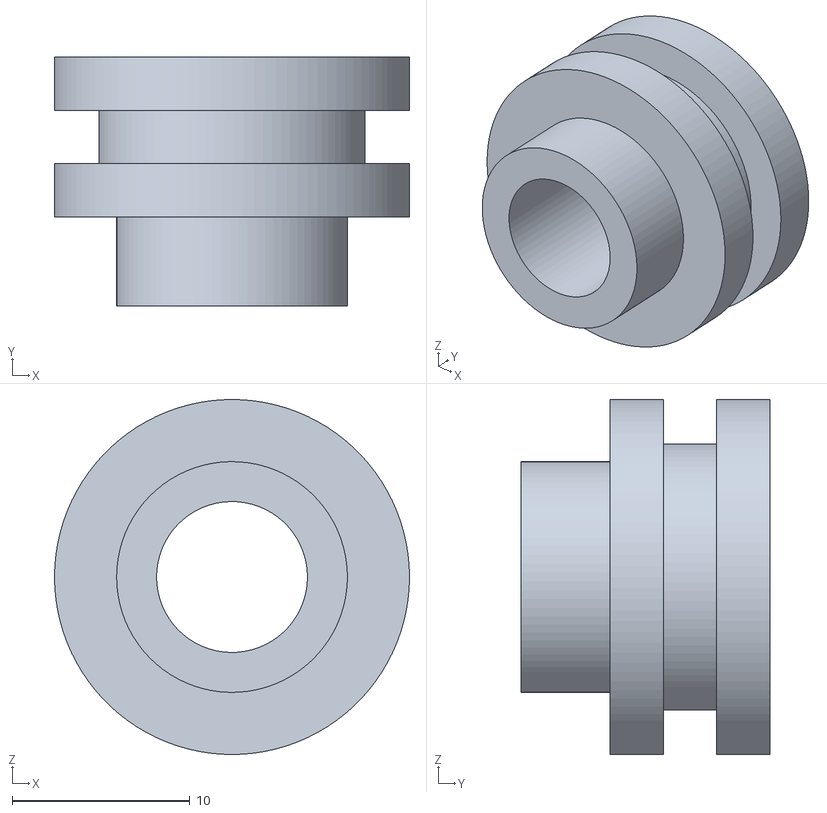
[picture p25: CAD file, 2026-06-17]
Projetos Mecânicos/poliaMenor_1,5.stl
20.0 x 14.0 x 20.0

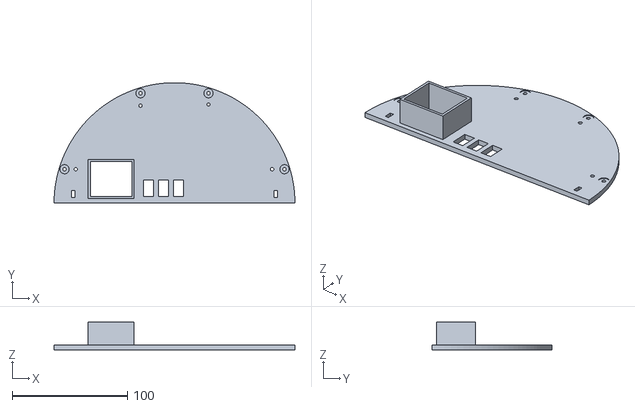
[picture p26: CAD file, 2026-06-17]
Projetos Mecânicos/chassi_soccer_cima.stl
209.0 x 104.5 x 24.0

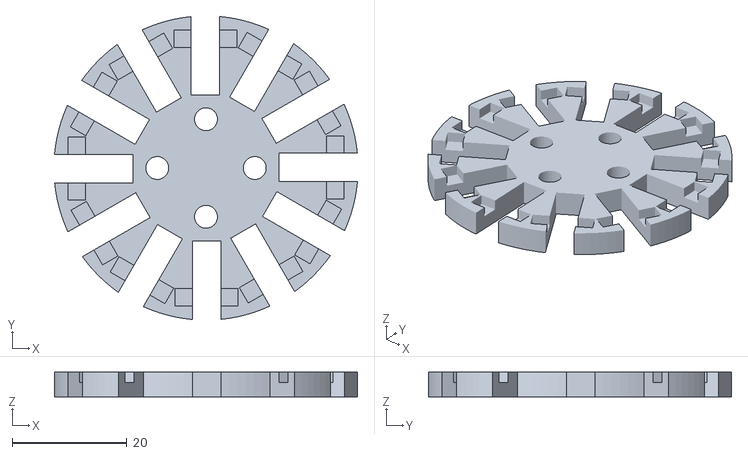
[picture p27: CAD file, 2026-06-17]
Projetos Mecânicos/omni_53.stl
52.8 x 52.8 x 4.30

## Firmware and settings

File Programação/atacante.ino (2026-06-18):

#include <Wire.h>
#include <Adafruit_Sensor.h>
#include <Adafruit_BNO055.h>
#include <utility/imumaths.h>
#include <HTInfraredSeeker.h>
#include <string.h>
// =========================
// BNO055
// =========================
Adafruit_BNO055 bno = Adafruit_BNO055(55);

bool  bnoCalibrado    = false;
float anguloRobo      = 0;
float offsetOrientacao = 0.0;   // ← offset do zero virtual
bool  calibrar        = 1;

void bno_calibrar() {
  Serial.println("Calibrando BNO055... aguarde.");
  uint8_t sys, gyro, accel, mag;
  while (true) {
    bno.getCalibration(&sys, &gyro, &accel, &mag);
    Serial.print("SYS:"); Serial.print(sys);
    Serial.print(" G:");  Serial.print(gyro);
    Serial.print(" A:");  Serial.print(accel);
    Serial.print(" M:");  Serial.println(mag);
    if (mag >= 2 && gyro >= 2) {
      bnoCalibrado = true;
      Serial.println(">>> BNO055 CALIBRADO - SISTEMA PRONTO <<<");
      break;
    }
    delay(200);
  }
}

// Zera a orientação: o yaw actual passa a ser 0
void zerarOrientacao() {
  imu::Vector<3> euler = bno.getVector(Adafruit_BNO055::VECTOR_EULER);
  offsetOrientacao = euler.x();
  Serial.print("Orientacao zerada. Novo offset: ");
  Serial.println(offsetOrientacao);
}

// Retorna yaw relativo ao zero virtual: -180 a +180
// 0 = frente definida pelo ultimo "zerar", positivo = direita, negativo = esquerda
float lerOrientacao() {
  imu::Vector<3> euler = bno.getVector(Adafruit_BNO055::VECTOR_EULER);
  float yaw = euler.x() - offsetOrientacao;
  while (yaw >  180.0) yaw -= 360.0;
  while (yaw < -180.0) yaw += 360.0;
  anguloRobo = yaw;
  return yaw;
}

// =========================
// VARIAVEIS IR
// =========================
int ballDirecao;
int ballIntens;
// variável global — coloque junto das outras globais no topo
int ballIntensAnterior = 0;
// =========================
// PINOS MOTORES
// =========================
#define M1_IN1 36
#define M1_IN2 38
#define M1_PWM 8

#define M2_IN1 22
#define M2_IN2 24
#define M2_PWM 3

#define M3_IN1 45
#define M3_IN2 47
#define M3_PWM 12

#define M4_IN1 28
#define M4_IN2 26
#define M4_PWM 4

#define MOTOR1_DIR 1
#define MOTOR2_DIR 1
#define MOTOR3_DIR 1
#define MOTOR4_DIR 1

#define DRIBBLER_PIN 34
#define SWITCH_PIN   48
#define KICKER_PIN   44

// =========================
// ULTRASSÔNICOS HC-SR04
// =========================
#define ECHO_ESQ  37
#define TRIG_ESQ  39
#define ECHO_TRAS 41
#define TRIG_TRAS 43
#define ECHO_DIR  33
#define TRIG_DIR  35

// =========================
// LDR
// =========================
#define luzEsq    53
#define luzFrente 52
#define luzDir    30
#define luzTras   49

#define botao 31

// =========================
// ULTRASSÔNICO - LEITURA
// =========================
float lerDistancia(int trigPin, int echoPin) {
  digitalWrite(trigPin, LOW);
  delayMicroseconds(2);
  digitalWrite(trigPin, HIGH);
  delayMicroseconds(10);
  digitalWrite(trigPin, LOW);
  long duracao = pulseIn(echoPin, HIGH, 30000);
  if (duracao == 0) return -1;
  return duracao * 0.0343 / 2.0;
}

float lerEsq()  { return lerDistancia(TRIG_ESQ,  ECHO_ESQ);  }
float lerTras() { return lerDistancia(TRIG_TRAS, ECHO_TRAS); }
float lerDir()  { return lerDistancia(TRIG_DIR,  ECHO_DIR);  }

// =========================
// LDR - LEITURA
// =========================
int lerLuzEsq()    { return digitalRead(luzEsq);    }
int lerLuzFrente() { return digitalRead(luzFrente); }
int lerLuzDir()    { return digitalRead(luzDir);    }
int lerLuzTras()   { return digitalRead(luzTras);   }



void mostrarLDRs() {
  Serial.print("Esq: ");       Serial.print(lerLuzEsq());
  Serial.print(" | Frente: "); Serial.print(lerLuzFrente());
  Serial.print(" | Dir: ");    Serial.print(lerLuzDir());
  Serial.print(" | Tras: ");   Serial.println(lerLuzTras());
}

// =========================
// SETUP
// =========================

// =========================
// CONTROLE DE MOTORES
// =========================
void motorWrite(int in1, int in2, int pwmPin, int speedValue) {
  speedValue = constrain(speedValue, -255, 255);
  if (speedValue > 0) {
    digitalWrite(in1, HIGH); digitalWrite(in2, LOW);
    analogWrite(pwmPin, speedValue);
  } else if (speedValue < 0) {
    digitalWrite(in1, LOW);  digitalWrite(in2, HIGH);
    analogWrite(pwmPin, -speedValue);
  } else {
    digitalWrite(in1, LOW);  digitalWrite(in2, LOW);
    analogWrite(pwmPin, 0);
  }
}

void setMotor(int motor, int speedValue) {
  switch (motor) {
    case 1: motorWrite(M1_IN1, M1_IN2, M1_PWM, speedValue * MOTOR1_DIR); break;
    case 2: motorWrite(M2_IN1, M2_IN2, M2_PWM, speedValue * MOTOR2_DIR ); break;
    case 3: motorWrite(M3_IN1, M3_IN2, M3_PWM, speedValue * MOTOR3_DIR); break;
    case 4: motorWrite(M4_IN1, M4_IN2, M4_PWM, speedValue * MOTOR4_DIR); break;
  }
}

void stopRobot() { setMotor(1,0); setMotor(2,0); setMotor(3,0); setMotor(4,0); }

void front(int s) { setMotor(1,-s); setMotor(2, s); setMotor(3,-s); setMotor(4, s *1.4); }
void back(int s)  { setMotor(1, s); setMotor(2,-s); setMotor(3, s); setMotor(4,-s); }
void left(int s)  { setMotor(1, s); setMotor(2, s); setMotor(3,-s); setMotor(4,-s *1.4); }
void right(int s) { setMotor(1,-s); setMotor(2,-s); setMotor(3, s); setMotor(4, s); }

void rotate(int s, int dir) {
  setMotor(1,-s*dir); setMotor(2,-s*dir);
  setMotor(3,-s*dir); setMotor(4,-s*dir);
}
void diagonalLeft(int s, int dir) {
  setMotor(1,0); setMotor(2, s*dir); setMotor(3,-s*dir); setMotor(4,0);
}
void diagonalRight(int s, int dir) {
  setMotor(1,-s*dir); setMotor(2,0); setMotor(3,0); setMotor(4, s*dir);
}
void moveRobot(int x, int y, int rot) {
  int m1 = -y - x - rot;
  int m2 =  y - x - rot;
  int m3 = -y + x - rot;
  int m4 =  y + x - rot;

  int maxValue = max(max(abs(m1), abs(m2)), max(abs(m3), abs(m4)));
  if (maxValue > 255) {
    float escala = 255.0 / maxValue;  // ← float, não divisão inteira
    m1 = (int)(m1 * escala);
    m2 = (int)(m2 * escala);
    m3 = (int)(m3 * escala);
    m4 = (int)(m4 * escala);
  }

  setMotor(1, m1);
  setMotor(2, m2);
  setMotor(3, m3);
  setMotor(4, m4);
}
void setup() {

  int inPins[] = {
    M1_IN1, M1_IN2,   // 38, 36
    M2_IN1, M2_IN2,   // 22, 24
    M3_IN1, M3_IN2,   // 45, 47
    M4_IN1, M4_IN2    // 26, 28
  };
  for (int i = 0; i < 8; i++) {
    pinMode(inPins[i], OUTPUT);
    digitalWrite(inPins[i], LOW);
  }

  // ── Força PWM = 0 explicitamente ──
  int pwmPins[] = { M1_PWM, M2_PWM, M3_PWM, M4_PWM }; // 8, 10, 9, 11
  for (int i = 0; i < 4; i++) {
    pinMode(pwmPins[i], OUTPUT);
    digitalWrite(pwmPins[i], LOW); // antes do analogWrite, garante LOW
    analogWrite(pwmPins[i], 0);
  }

  Serial.begin(115200);
  Wire.begin();


  stopRobot();
  pinMode(DRIBBLER_PIN, OUTPUT);
  pinMode(SWITCH_PIN,   INPUT_PULLUP);
  pinMode(KICKER_PIN, OUTPUT);
  pinMode(TRIG_ESQ,  OUTPUT); pinMode(ECHO_ESQ,  INPUT);
  pinMode(TRIG_TRAS, OUTPUT); pinMode(ECHO_TRAS, INPUT);
  pinMode(TRIG_DIR,  OUTPUT); pinMode(ECHO_DIR,  INPUT);
  pinMode(botao, INPUT_PULLUP);

  if (!bno.begin()) {
    Serial.println("ERRO: BNO055 nao encontrado! Verifique a ligacao.");
    while (1);
  }
  delay(1000);
  bno.setMode(OPERATION_MODE_NDOF);
  digitalWrite(DRIBBLER_PIN,HIGH);
  digitalWrite(KICKER_PIN, HIGH);
  if (calibrar) { bno_calibrar(); }

  // Zera a orientação logo após calibrar (define a posição inicial como frente)
  zerarOrientacao();

  Serial.println("Sistema iniciado");
}

// =========================
// IR SEEKER
// =========================
// =========================
// SEGUIR BOLA (IR Seeker)
// =========================
// =========================
// SEGUIR BOLA (IR Seeker) — avanço contínuo com correção de orientação
// =========================
#define BALL_KP_ROT             45   // ganho proporcional da correção angular
#define BALL_VEL_FRENTE_MAX    255    // velocidade quando a bola está longe
#define BALL_VEL_FRENTE_MIN     145   // velocidade mínima quando está bem perto
#define BALL_VEL_ROT_MAX        185    // limite da correção de rotação
#define BALL_CENTRO              5
#define BALL_INTENS_MAX        150    // intensidade máxima do sensor
#define BALL_INTENS_PERTO       135    // intensidade a partir da qual já reduz bastante

void trackBall() {
  InfraredResult InfraredBall = InfraredSeeker::ReadAC();
  ballDirecao = InfraredBall.Direction;
  ballIntens  = InfraredBall.Strength;

  if (ballDirecao == 0) {
    stopRobot();
    return;
  }

  int erro = ballDirecao - BALL_CENTRO;

  // ── Correção de rotação proporcional ao erro ──
  int velRot = erro * BALL_KP_ROT;
  velRot = constrain(velRot, -BALL_VEL_ROT_MAX, BALL_VEL_ROT_MAX);

  // ── Velocidade de avanço: diminui conforme a bola se aproxima ──
  // Mapeia ballIntens (0..BALL_INTENS_MAX) → velFrente (MAX..MIN)
  int intensClamped = constrain(ballIntens, 0, BALL_INTENS_PERTO);
  int velFrente = map(intensClamped, 0, BALL_INTENS_PERTO, BALL_VEL_FRENTE_MAX, BALL_VEL_FRENTE_MIN);

  // ── Quando muito desalinhado, reduz ainda mais o avanço para não "fugir" da bola ──
  if (abs(erro) >= 2) {
    velFrente = velFrente * 0.7;
  }
  // ── Avança e corrige orientação simultaneamente ──
  moveRobot(0, velFrente, velRot);

  Serial.print("Dir:"); Serial.print(ballDirecao);
  Serial.print(" Erro:"); Serial.print(erro);
  Serial.print(" Intens:"); Serial.print(ballIntens);
  Serial.print(" VelF:"); Serial.print(velFrente);
  Serial.print(" VelR:"); Serial.println(velRot);
}


// =========================
// EVITAR LINHA — não-bloqueante
// =========================
// =========================
// EVITAR LINHA — não-bloqueante com filtro anti-ruído
// =========================
#define LINHA_VEL           255
#define LINHA_TEMPO         90   // ms de recuo
#define LINHA_CONFIRMACOES   3   // leituras consecutivas para confirmar linha

enum EstadoRobo { SEGUIR_BOLA, EVITAR_LINHA };
EstadoRobo estadoAtual = SEGUIR_BOLA;
unsigned long tempoInicioLinha = 0;

enum MovimentoLinha { MOV_BACK, MOV_FRONT, MOV_LEFT, MOV_RIGHT,
                      MOV_DIAG_LD, MOV_DIAG_LE, MOV_DIAG_TD, MOV_DIAG_TE };
MovimentoLinha movimentoLinha;

// Contadores de confirmação por sensor
int contEsq = 0, contFrente = 0, contDir = 0, contTras = 0;

bool gerenciarLinha() {
  bool rawEsq    = (lerLuzEsq()    == 0);
  bool rawFrente = (lerLuzFrente() == 0);
  bool rawDir    = (lerLuzDir()    == 0);
  bool rawTras   = (lerLuzTras()   == 0);

  // ── Atualiza contadores de confirmação ──
  contEsq    = rawEsq    ? contEsq    + 1 : 0;
  contFrente = rawFrente ? contFrente + 1 : 0;
  contDir    = rawDir    ? contDir    + 1 : 0;
  contTras   = rawTras   ? contTras   + 1 : 0;

  // Só considera "linha detectada" após N leituras consecutivas
  bool esq    = (contEsq    >= LINHA_CONFIRMACOES);
  bool frente = (contFrente >= LINHA_CONFIRMACOES);
  bool dir    = (contDir    >= LINHA_CONFIRMACOES);
  bool tras   = (contTras   >= LINHA_CONFIRMACOES);
  bool algumConfirmado = esq || frente || dir || tras;

  if (estadoAtual == SEGUIR_BOLA) {
    if (!algumConfirmado) return false;

    // Linha confirmada → define recuo e entra no estado
    tempoInicioLinha = millis();
    estadoAtual = EVITAR_LINHA;

    // Zera contadores para não reativar imediatamente
    contEsq = contFrente = contDir = contTras = 0;

    if      (frente && esq)  movimentoLinha = MOV_DIAG_LD;
    else if (frente && dir)  movimentoLinha = MOV_DIAG_LE;
    else if (tras   && esq)  movimentoLinha = MOV_DIAG_TD;
    else if (tras   && dir)  movimentoLinha = MOV_DIAG_TE;
    else if (frente)         movimentoLinha = MOV_BACK;
    else if (tras)           movimentoLinha = MOV_FRONT;
    else if (esq)            movimentoLinha = MOV_RIGHT;
    else                     movimentoLinha = MOV_LEFT;

    Serial.print("[LINHA CONFIRMADA] esq:"); Serial.print(esq);
    Serial.print(" frente:"); Serial.print(frente);
    Serial.print(" dir:"); Serial.print(dir);
    Serial.print(" tras:"); Serial.println(tras);
  }

  if (estadoAtual == EVITAR_LINHA) {
    switch (movimentoLinha) {
      case MOV_BACK:     back(LINHA_VEL);                 break;
      case MOV_FRONT:    front(LINHA_VEL);                break;
      case MOV_LEFT:     left(LINHA_VEL);                 break;
      case MOV_RIGHT:    right(LINHA_VEL);                break;
      case MOV_DIAG_LD:  diagonalRight(LINHA_VEL,  1);   break;
      case MOV_DIAG_LE:  diagonalLeft(LINHA_VEL,   1);   break;
      case MOV_DIAG_TD:  diagonalRight(LINHA_VEL, -1);   break;
      case MOV_DIAG_TE:  diagonalLeft(LINHA_VEL,  -1);   break;
    }

    // Sai só quando o tempo expirou — ignora se a linha sumiu antes
    if (millis() - tempoInicioLinha > LINHA_TEMPO) {
      estadoAtual = SEGUIR_BOLA;
    }
    return true;
  }
  return false;
}
// =========================
// SEGUIR BOLA XY — sem rotação proporcional ao IR
// Robô sempre mantém-se olhando para o ângulo 0 (definido pelo botão)
// Direção (x,y) é definida pela posição da bola
// =========================
#define BALL_VEL_MAX        255
#define BALL_VEL_MIN         80

// direções do IR seeker (1..9), CENTRO=5
// 1,2,3 = esquerda | 4,5,6 = frente | 7,8,9 = direita
// Aproximação de "atrás": quando intensidade muito baixa OU não detecta (0)
#define ROT_KP             2.0
#define ROT_VELOCIDADE_MIN  56
#define ROT_VELOCIDADE_MAX 80
#define ROT_TOLERANCIA     4.0
// =========================
// TRACKBALL XY — movimentos discretos + PID de orientação para manter 0°
// "Ir atrás da bola": quando a bola está muito perto (intensidade alta) e alinhada,
// o robô recua/desacelera em vez de continuar avançando sobre ela
// =========================
// ROTAÇÃO PARA ÂNGULO ALVO
// =========================

float calcularErro(float anguloAtual, float anguloAlvo) {
  float erro = anguloAlvo - anguloAtual;
  while (erro >  180) erro -= 360;
  while (erro < -180) erro += 360;
  return erro;
}

bool rotacionarParaAngulo(float anguloAlvo) {
  float atual = lerOrientacao();   // já usa o offset automaticamente
  float erro  = calcularErro(atual, anguloAlvo);

  Serial.print("Yaw: "); Serial.print(atual);
  Serial.print(" | Erro: "); Serial.println(erro);

  if (abs(erro) <= ROT_TOLERANCIA) {
    stopRobot();
    return true;
  }

  int velocidade = (int)(abs(erro) * ROT_KP);
  velocidade = constrain(velocidade, ROT_VELOCIDADE_MIN, ROT_VELOCIDADE_MAX);
  int direcao = (erro > 0) ? 1 : -1;
  rotate(velocidade, direcao);
  return false;
}

// =========================
// DETECÇÃO DE BORDA DO BOTÃO
// =========================
bool botaoAnterior = HIGH;   // pull-up → repouso = HIGH
bool setado = false;
void verificarBotaoZero() {
  bool botaoAtual = digitalRead(botao);
  // Borda HIGH → LOW = botão acabou de ser pressionado
  if (botaoAnterior == HIGH && botaoAtual == LOW && setado == false) {
    //executarChute(1, 50);
    setado = true;
    zerarOrientacao();
  }
  botaoAnterior = botaoAtual;
}

// =========================
// LOOP
// =========================
// =========================
// MOVER ATÉ DISTÂNCIA (ULTRASSÔNICO)
// =========================
#define DIST_KP            4.0
#define DIST_TOLERANCIA    1.5   // cm — considera "chegou" dentro dessa margem
#define DIST_VEL_MIN       70
#define DIST_VEL_MAX       180

// ── Move usando o ultrassônico ESQUERDO como referência ──
// distanciaAlvo: distância desejada em cm entre o robô e o obstáculo à esquerda
// Retorna true quando atingir a distância (dentro da tolerância)
bool moverAteDistanciaEsq(float distanciaAlvo) {
  float atual = lerEsq();

  // Sensor sem leitura válida → não move, evita decisão errada
  if (atual < 0) {
    stopRobot();
    return false;
  }

  float erro = atual - distanciaAlvo;  // positivo = está mais longe que o alvo → precisa se aproximar (ir para a esquerda)

  Serial.print("[ESQ] Dist: "); Serial.print(atual);
  Serial.print(" | Alvo: "); Serial.print(distanciaAlvo);
  Serial.print(" | Erro: "); Serial.println(erro);

  if (abs(erro) <= DIST_TOLERANCIA) {
    stopRobot();
    if (abs(calcularErro(lerOrientacao(), 0)) > 10.0) {
  rotacionarParaAngulo(0);
  }
    return true;
  }

  int velocidade = (int)(abs(erro) * DIST_KP);
  velocidade = constrain(velocidade, DIST_VEL_MIN, DIST_VEL_MAX);

  // erro > 0 → muito longe do obstáculo esquerdo → mover para a esquerda (aproximar)
  // erro < 0 → muito perto do obstáculo esquerdo → mover para a direita (afastar)
  if (erro > 0) left(velocidade);
  else           right(velocidade);

  return false;
}

// ── Move usando o ultrassônico DIREITO como referência ──
bool moverAteDistanciaDir(float distanciaAlvo) {
  float atual = lerDir();

  if (atual < 0) {
    stopRobot();
    return false;
  }

  float erro = atual - distanciaAlvo;

  Serial.print("[DIR] Dist: "); Serial.print(atual);
  Serial.print(" | Alvo: "); Serial.print(distanciaAlvo);
  Serial.print(" | Erro: "); Serial.println(erro);

  if (abs(erro) <= DIST_TOLERANCIA) {
    stopRobot();
    if (abs(calcularErro(lerOrientacao(), 0)) > 10.0) {
  rotacionarParaAngulo(0);
  }
    return true;
  }

  int velocidade = (int)(abs(erro) * DIST_KP);
  velocidade = constrain(velocidade, DIST_VEL_MIN, DIST_VEL_MAX);

  // erro > 0 → muito longe do obstáculo direito → mover para a direita (aproximar)
  // erro < 0 → muito perto do obstáculo direito → mover para a esquerda (afastar)
  if (erro > 0) right(velocidade);
  else           left(velocidade);

  return false;
}

// ── Move usando o ultrassônico TRASEIRO como referência ──
bool moverAteDistanciaTras(float distanciaAlvo) {
  float atual = lerTras();

  if (atual < 0) {
    stopRobot();
    return false;
  }

  float erro = atual - distanciaAlvo;

  Serial.print("[TRAS] Dist: "); Serial.print(atual);
  Serial.print(" | Alvo: "); Serial.print(distanciaAlvo);
  Serial.print(" | Erro: "); Serial.println(erro);

  if (abs(erro) <= DIST_TOLERANCIA) {
    stopRobot();
    if (abs(calcularErro(lerOrientacao(), 0)) > 10.0) {
  rotacionarParaAngulo(0);
  }
    return true;
  }

  int velocidade = (int)(abs(erro) * DIST_KP);
  velocidade = constrain(velocidade, DIST_VEL_MIN, DIST_VEL_MAX);

  // erro > 0 → muito longe do obstáculo traseiro → mover para trás (aproximar)
  // erro < 0 → muito perto do obstáculo traseiro → mover para frente (afastar)
  if (erro > 0) back(velocidade);
  else           front(velocidade);

  return false;
}

// Calcula a correção de rotação (velRot) para manter anguloAlvo


// ── FRENTE com PID ──
// forca: velocidade de avanço (0-255)
// anguloAlvo: ângulo a manter (graus, referência do zero do botão)

// ── TRÁS com PID ──


// ── ESQUERDA com PID ──

// ── DIREITA com PID ──

// ── DIAGONAL com PID ──
// direcao: "fe"=frente-esquerda, "fd"=frente-direita, "te"=trás-esquerda, "td"=trás-direita

void mostrarLinhas() {
  Serial.print("Esq:");    Serial.print(lerLuzEsq());
  Serial.print(" Frente:"); Serial.print(lerLuzFrente());
  Serial.print(" Dir:");    Serial.print(lerLuzDir());
  Serial.print(" Tras:");   Serial.println(lerLuzTras());
}
// =========================
// FUGIR DA LINHA — movimento oposto ao sensor ativado
// =========================
#define FUGA_VEL  200
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
void loop() {
  // Verifica se o botão foi pressionado para zerar orientação
  verificarBotaoZero();
  InfraredResult InfraredBall = InfraredSeeker::ReadAC();
  ballDirecao = InfraredBall.Direction;
  ballIntens  = InfraredBall.Strength;
  
  //back(100);
 // delay(2000);
  //stopRobot();
 // delay(2000);
 // back(100);
  //delay(2000);
 // stopRobot();
  //delay(2000);
  Serial.println(digitalRead(botao));
  if (digitalRead(botao)) {
    digitalWrite(DRIBBLER_PIN, HIGH);
  digitalWrite(KICKER_PIN, HIGH);
    
    stopRobot();
    //Serial.println(digitalRead(botao));
    //resetPidOrientacao();
    //Serial.print("Esq: ");
    //Serial.println(lerOrientacao());
    //rotacionarParaAngulo(90);
  } else {
    digitalWrite(DRIBBLER_PIN,HIGH);
  digitalWrite(KICKER_PIN, HIGH);
  //fugirDaLinha();

   //float distEsq  = lerEsq();
   // float distDir  = lerDir();
    //float distTras = lerTras();
    //Serial.println(distTras);
    /*
    if (distEsq > 0 && distEsq < 2.5) {
      right(200);
      delay(10);
      return;
    }
    if (distDir > 0 && distDir < 2.5) {
      left(200);
      delay(10);
      return;
    }
    */
 //   if (abs(calcularErro(lerOrientacao(), 0)) > 10.0) {
 // rotacionarParaAngulo(0);
 // }
 // Serial.println(lerOrientacao());
  /*
    if (distTras > 0 && distTras < 2.5) {
      front(100);
      delay(10);
      return;
    }
    */
   

  trackBallOrientado();
  float distTras = lerTras();
    if (distTras > 0 && distTras > 160.0) {
      back(200);
      delay(10);
      return;
    }
    else if (distTras <35 && distTras >0){
      front(200);
      delay(10);
      return;  

    }

  float distEsq = lerEsq();
  if (distEsq > 0 && distEsq < 15.0) {
    right(200);
    delay(10);
    return;
  }

  float distDir = lerDir();
  if (distDir > 0 && distDir < 15.0) {
    left(200);
    delay(10);
    return;
  }
 // moverAteDistanciaEsq(15);
 //fugirDaLinha();
 //Serial.println(lerDir());
 // Serial.println(lerDir());
 // rotacionarParaAngulo(0);
  /*
  diagonalRight(150, 1);
  delay(2000);
  stopRobot();
  delay(2000);
  diagonalRight(150, -1);
  delay(2000);
  stopRobot();
  delay(2000);
  diagonalLeft(150, 1);
  delay(2000);
  stopRobot();
  delay(2000);
  diagonalLeft(150, -1);
  delay(2000);
  stopRobot();
  delay(2000);
  */
  //mostrarLinhas();
    //digitalWrite(DRIBBLER_PIN, HIGH);
    //digitalWrite(KICKER_PIN, HIGH);
    //Serial.println(digitalRead(botao));
    //moverAteDistanciaEsq(15);
    //frontPID(90,0);
    //front(90);
    //stopRobot();
    //digitalWrite(DRIBBLER_PIN, HIGH);
   // Serial.println(digitalRead(SWITCH_PIN));
    //Serial.println(lerOrientacao());
   // Serial.println(digitalRead(SWITCH_PIN));
  // Serial.println(lerLuzDir());
    
   // moveRobot(0,100,0);
   //rotacionarParaAngulo(90);
   // if (!gerenciarLinha()) {
    //  trackBall();   // ou trackBallXY()
   // }
   //trackBall();
 
  }
  Serial.println(ballIntens);
  Serial.println(ballDirecao);
  delay(10);
}

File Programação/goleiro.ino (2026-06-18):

#include <Wire.h>
#include <Adafruit_Sensor.h>
#include <Adafruit_BNO055.h>
#include <utility/imumaths.h>
#include <string.h>

// =========================
// BNO055
// =========================
Adafruit_BNO055 bno = Adafruit_BNO055(55);

bool  bnoCalibrado     = false;
float anguloRobo       = 0;
float offsetOrientacao = 0.0;  // Offset do zero virtual de orientação
bool  calibrar         = 0;    // Se 1, aguarda calibração completa no setup

void bno_calibrar() {
  Serial.println("Calibrando BNO055... aguarde.");
  uint8_t sys, gyro, accel, mag;
  while (true) {
    bno.getCalibration(&sys, &gyro, &accel, &mag);
    Serial.print("SYS:"); Serial.print(sys);
    Serial.print(" G:");  Serial.print(gyro);
    Serial.print(" A:");  Serial.print(accel);
    Serial.print(" M:");  Serial.println(mag);
    if (mag >= 2 && gyro >= 2) {
      bnoCalibrado = true;
      Serial.println(">>> BNO055 CALIBRADO - SISTEMA PRONTO <<<");
      break;
    }
    delay(200);
  }
}

// Zera a orientação: o yaw atual passa a ser considerado como 0 graus (frente)
void zerarOrientacao() {
  imu::Vector<3> euler = bno.getVector(Adafruit_BNO055::VECTOR_EULER);
  offsetOrientacao = euler.x();
  Serial.print("Orientacao zerada. Novo offset: ");
  Serial.println(offsetOrientacao);
}

// Retorna yaw relativo ao zero virtual: -180 a +180 graus
// 0 = frente definida pelo último "zerar", positivo = direita, negativo = esquerda
float lerOrientacao() {
  imu::Vector<3> euler = bno.getVector(Adafruit_BNO055::VECTOR_EULER);
  float yaw = euler.x() - offsetOrientacao;
  while (yaw >  180.0) yaw -= 360.0;
  while (yaw < -180.0) yaw += 360.0;
  anguloRobo = yaw;
  return yaw;
}

// =======================================================================
// SISTEMA DE RECOVERY DE POSIÇÃO
// =======================================================================
// Distâncias de referência capturadas no startup (posição central ideal)
float distanciaReferenciaEsq = 0.0f;
float distanciaReferenciaDir = 0.0f;

// =======================================================================
// VARIÁVEIS DOS SENSORES IR FRONTAIS (BOLA)
// =======================================================================
const uint8_t NUM_IR = 5;
const uint8_t PIN_IR[5] = { 40, 42, 44, 46, 32 };
// [0] Extrema Esquerda, [1] Centro-Esq, [2] Centro, [3] Centro-Dir, [4] Extrema Dir
//
// ATENÇÃO: PIN_IR[2] = pino 44, mesmo pino que KICKER_PIN.
// Conflito de hardware pré-existente — não pode ser corrigido via software sem
// alterar o mapeamento físico. Preservado como estava no código original.
const int IR_DETECTADO = LOW;

// =========================
// PINOS MOTORES
// =========================
#define M1_IN1 38
#define M1_IN2 36
#define M1_PWM 8

#define M2_IN1 22
#define M2_IN2 24
#define M2_PWM 10

#define M3_IN1 45
#define M3_IN2 47
#define M3_PWM 9

#define M4_IN1 28
#define M4_IN2 26
#define M4_PWM 11

#define MOTOR1_DIR 1
#define MOTOR2_DIR 1
#define MOTOR3_DIR 1
#define MOTOR4_DIR 1

#define SWITCH_PIN  48   // Declarado, não utilizado no loop — preservado
#define KICKER_PIN  44   // ATENÇÃO: conflito com PIN_IR[2] (pino 44)

// =========================
// ULTRASSÔNICOS HC-SR04
// =========================
#define ECHO_ESQ  37
#define TRIG_ESQ  39
#define ECHO_TRAS 41
#define TRIG_TRAS 43
#define ECHO_DIR  33
#define TRIG_DIR  35

// =========================
// LDR / SENSORES DE LINHA
// =========================
// Pinos preservados e inicializados, mas NÃO utilizados como trava de movimento.
// Removidos da lógica de fronteira lateral conforme requisito do projeto.
#define luzEsq    52
#define luzFrente 53
#define luzDir    49
#define luzTras   30

#define botao 31


// PID de distância por ultrassônico
#define DIST_KP           8.0

// Tolerância em cm
#define DIST_TOLERANCIA   2.0

// Limites de velocidade
#define DIST_VEL_MIN      40
#define DIST_VEL_MAX      150

#define BALL_VEL_MAX        255
#define BALL_VEL_MIN         80

// direções do IR seeker (1..9), CENTRO=5
// 1,2,3 = esquerda | 4,5,6 = frente | 7,8,9 = direita
// Aproximação de "atrás": quando intensidade muito baixa OU não detecta (0)
#define ROT_KP             2.1
#define ROT_VELOCIDADE_MIN  56
#define ROT_VELOCIDADE_MAX 80
#define ROT_TOLERANCIA     4.0
// =========================
// TRACKBALL XY — movimentos discretos + PID de orientação para manter 0°
// "Ir atrás da bola": quando a bola está muito perto (intensidade alta) e alinhada,
// o robô recua/desacelera em vez de continuar avançando sobre ela
// =========================
#define TBXY_VEL_FRENTE     200
#define TBXY_VEL_LATERAL    220
#define TBXY_VEL_DIAGONAL   200
#define TBXY_VEL_RECUO      120
#define TBXY_INTENS_MUITO_PERTO  140   // acima disso, considera "na bola" → recua

// =======================================================================
// PARÂMETROS DE FRONTEIRA ULTRASSÔNICA (ajuste antes da competição)
// =======================================================================

// Distância mínima ao lado esquerdo (cm). Abaixo deste valor, bloqueia movimento à esquerda.
// Cálculo de referência: área de pênalti = 70 cm, robô = 20 cm → ~25 cm de folga.
// ASSUNÇÃO: valor padrão 25 cm. Medir fisicamente antes da competição.
#define LIMITE_ESQ_CM   25.0f

// Distância mínima ao lado direito (cm). Abaixo deste valor, bloqueia movimento à direita.
// Simétrico ao limite esquerdo.
// ASSUNÇÃO: valor padrão 25 cm. Medir fisicamente antes da competição.
#define LIMITE_DIR_CM   25.0f

// Distância mínima à parede traseira (cm). Abaixo deste valor, bloqueia movimento para trás.
// ASSUNÇÃO: valor padrão 20 cm. Distância traseira NÃO fornecida — MEDIR antes da competição.
#define LIMITE_TRAS_CM  20.0f

// Distância máxima válida para leitura ultrassônica (cm).
// Leituras acima deste valor são consideradas erro de reflexão ou fora de alcance.
#define ULTRASSONICO_MAX_CM  200.0f

// =======================================================================
// PARÂMETROS DE CONTROLE DE ORIENTAÇÃO (ajuste se necessário)
// =======================================================================

// Ganho proporcional para correção de yaw.
// Erro de 10° → correção de ~15 unidades PWM com Kp=1.5.
// ASSUNÇÃO: valor inicial 1.5. Ajustar em testes se o robô oscilar.
#define KP_ORIENTACAO   1.5f

// Zona morta de orientação (graus). Erros menores que este valor são ignorados.
// Evita micro-correções por ruído do IMU.
// ASSUNÇÃO: 2.0 graus.
#define ZONA_MORTA_GRAUS  2.0f

// Correção máxima de rotação aplicada ao moveRobot() (unidades PWM).
// Limita o quanto a correção de orientação pode interferir no movimento lateral.
// ASSUNÇÃO: 60 unidades PWM.
#define MAX_CORRECAO_ROT  60

// =========================
// VELOCIDADE DE RASTREIO
// =========================
#define VELOCIDADE_LATERAL 255

// Velocidade de retorno à posição de referência.
// Mais lento que VELOCIDADE_LATERAL para evitar overshooting.
#define VELOCIDADE_RECOVERY  80
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
